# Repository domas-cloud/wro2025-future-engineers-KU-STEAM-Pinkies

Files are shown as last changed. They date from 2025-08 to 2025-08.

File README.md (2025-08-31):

# 🤖 WRO 2025 Future Engineers – KU STEAM Pinkies

   

Welcome to our official repository for **WRO 2025 Future Engineers Challenge**!  

We are **KU STEAM Pinkies**, a passionate team of young engineers building an **autonomous robot car** capable of navigating real-world tracks, avoiding obstacles, and detecting checkpoints.

---

## 👥 Team Introduction

**Team Members & Roles**
- **Marius** – Programmer & Mechanical Designer  
- **Domas** – Manager, Marketing & Testing  
- **Jonas** – Electronics Specialist & Designer  

**Our Goal:**  
To design and build a reliable autonomous robot that can perceive its environment, make decisions in real time, and drive smoothly and safely.

---

## 📚 Documentation

Our development process is fully documented:

- 🧠 [Brainstorming](docs/brainstorming.md)
- 📝 [Planning](docs/planning.md)
- ⚙️ [Hardware](docs/hardware.md)
- 🛠️ [Mechanical Design](docs/design.md)
- ⚡ [Power & Sense Management](docs/power_management.md)
- 💻 [Software / Code](docs/code.md)
- 🧪 [Testing](docs/testing.md)
- 📊 [Evaluation](docs/evaluation.md)
- ❗ [Encountered Problems and Solutions](docs/Encountered_Problems_and_Solutions.md)
 
---

## ⚙️ Hardware Overview

- **Arduino Mega 2560** – main controller (sensors + decision-making)  
- **Raspberry Pi Zero 2** – handles camera vision, communicates with Arduino via Serial  
- **Adafruit Motor Shield V2** – motor driver (DC + Servo)  
- **TOF sensors (VL53L1X)** – distance & obstacle detection (front + sides)  
- **TCS34725 Color Sensor** – detects orange/blue track lines for checkpoint counting  
- **Servo motor (SG90)** – precise steering  
- **DC motor + gear reduction + bearings** – smooth driving with torque optimization  
- **Li-ion batteries** – powering Arduino + motors  
- **Power bank** – powering Raspberry Pi for stable 5V  

---

## 💻 Software Overview

The software is based on a **three-layer architecture**:

1. **Obstacle Detection** (sensors)  
2. **Navigation** (error calculation + decision making)  
3. **Control** (PD steering + motor speed regulation)  

### 🔑 Step-by-Step Flow
1. **Sensor Reading** – TOF + color sensor data  
2. **Error Calculation** – compare measured distance vs desired trajectory  
3. **PD Control** – proportional + derivative parts for stable steering  
4. **Servo Steering** – adjusts angle based on PD output  
5. **Motor Update** – base speed / slow down / stop depending on obstacles  
6. **Obstacle Logic** – stop, bypass, or continue safely  

### 💬 Extra Features
- **Safety stop** if all sensors fail  
- **Servo angle limits** to avoid mechanical stress  
- **Base driving mode** if no obstacles detected  
- **Color sensor** counts **checkpoints** (orange & blue lines)  

---

## ▶️ How to Run the Code

### 1. Clone the Repository with Submodules
```bash
git clone --recurse-submodules https://github.com/domas-cloud/wro2025-future-engineers-KU-STEAM-Pinkies.git
cd wro2025-future-engineers-KU-STEAM-Pinkies
git submodule update --init --recursive
```

### 2. Open in PlatformIO
- Install [PlatformIO](https://platformio.org/) (VSCode extension or CLI).  
- Target board: **Arduino Mega 2560**.  

### 3. Build & Upload
```bash
pio run
pio run -t upload
```

### 4. Monitor Serial Output (optional)
```bash
pio device monitor
```

---

## 📚 Required Libraries

Make sure the following libraries are installed in PlatformIO or Arduino IDE:  

- `Adafruit Motor Shield V2 Library`  
- `Adafruit VL53L1X`  
- `Adafruit TCS34725`  
- `Wire` (I2C)  
- `Servo`  

---

## ⚠️ Limitations & Known Issues

### 1. Ultrasonic Sensors (Initial Tests)  
- In the early prototype, we used **HC-SR04 ultrasonic sensors**.  
- **Problems encountered:**  
  - Narrow field of view.  
  - Inaccurate measurements on uneven or angled surfaces.  
  - “Blind spots” in curves.  
- Because of these limitations, we switched to **VL53L1X TOF sensors**, which provide faster and more reliable distance readings.

### 2. TOF (VL53L1X) Sensors  
- Sometimes inaccurate on **very shiny** or **black matte** surfaces.  
- Multiple TOFs on the same I2C bus require **address reassignment** in software to avoid conflicts.  

### 3. TCS34725 Color Sensor  
- Strong ambient light can interfere with detection.  
- Close color shades (similar orange/blue tones) sometimes cause **false checkpoint counts**.  

### 4. PD Control (No Integral Part)  
- Without the integral (I) term, **steady-state error** may occur (e.g., robot stays closer to one wall).  
- In very sharp turns, PD sometimes results in **over-steering**.  

### 5. Mechanical Limitations  
- Single DC motor + gear system does not provide perfectly stable speed.  
- Bearings reduced friction, but on longer tracks, slight **speed fluctuations** remain.  

### 6. Raspberry Pi Zero 2  
- Too weak for **real-time image processing**.  
- Cannot run complex ML/AI models effectively.  

### 7. Power Supply Issues  
- When batteries are low, the **servo and DC motor** become unstable.  
- A **voltage monitoring system** would help stop the robot before malfunction.  

✅ Despite these limitations, the system is **robust enough for competition use**, and each issue points toward **clear upgrade paths** for future iterations.

---

## 🔮 Future Improvements

- Add an **integral part (I)** for full PID control  
- Implement **adaptive PID tuning** (self-adjusting Kp & Kd)  
- Improve obstacle avoidance with **dynamic path planning**  
- Use **machine learning** on Raspberry Pi to optimize driving  
- Add **IMU + encoders** for precise navigation  
- Implement **battery monitoring & current sensing** for reliability  

---

## ✅ Summary

Our robot behaves like a human driver:  
1. **Look** → read sensors (TOF + Color)  
2. **Decide** → calculate errors & detect obstacles  
3. **Act** → adjust steering + motor speed  

With PD control, the car drives smoothly, avoids obstacles, and counts checkpoints reliably.  

---

## 📜 License
This project is licensed under the **MIT License** – feel free to use, modify, and share with credit.

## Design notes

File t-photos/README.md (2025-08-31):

# KU Steam Pinkies Team

oficial

Here you can see the team members' arrangement:

- **Domas** – left  
- **Marius** – center  
- **Jonas** – right

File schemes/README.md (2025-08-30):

# 🔌 Electronics Diagrams

We designed and tested two wiring configurations for our robot: one with **5 ToF sensors only**, and one with **3 ToFs + IMU**. Both share the same **core PD control algorithm** – only the sensor inputs differ.

---

## 📐 Variant A – Without IMU (5× ToF)

**Description:**  
- **Arduino Mega 2560** is the main controller.  
- **5× VL53L1X ToF sensors** connected to the I²C bus (SDA/SCL).  
- Each ToF has an **XSHUT** line connected to a digital pin on Arduino to assign unique I²C addresses during initialization.  
- Optional **GPIO1/INT** lines can be connected for interrupts (not required).  
- **Motor/Servo module** controls the steering servo (PWM) and the DC drive motor (PWM).  

**Power:**  
- ToFs powered at 3.3 V, common GND with Arduino.  
- Servo + motor require stable 5–6 V supply (separate BEC recommended).  

📄 *See schematic:* [`Without IMU.pdf`](Without%20IMU.pdf)

---

## 📐 Variant B – With IMU (3× ToF + IMU)

**Description:**  
- **Arduino Mega 2560** is again the main controller.  
- **3× VL53L1X ToFs** on the same I²C bus.  
- **IMU sensor** (gyroscope + accelerometer) also connected to I²C, providing yaw/gyro data.  
- ToF **XSHUT** pins used for unique addressing as before.  
- **IMU INT** (interrupt) optionally connected to a digital input for faster reaction.  
- **Motor/Servo module** wiring unchanged (PWM).  

**Power:**  
- IMU powered at 3.3 V, ToFs also at 3.3 V.  
- Common GND required.  
- Servo/motor powered separately as in Variant A.  

📄 *See schematic:* [`with IMU.pdf`](with%20IMU.pdf)

---

## ⚖️ Comparison

| Feature | Without IMU (5 ToFs) | With IMU (3 ToFs + IMU) |
|---|---|---|
| Distance sensing | 5 directions (wider view)  | 3 directions + orientation |
| Orientation correction | From ToF geometry | From IMU (yaw/gyro) |
| I²C addressing | 5× ToF via **XSHUT** | 3× ToF via **XSHUT**, IMU fixed address |
| Wiring complexity | More ToFs, more lines | Fewer ToFs, extra IMU |
| Algorithm | **Same PD control** | **Same PD control** |

---

## 📝 Notes

- **Algorithm remains unchanged** in both cases (PD wall-following + motor control).  
- The only difference is the **sensor input**: either 5 ToFs, or 3 ToFs + IMU fusion.  
- Using IMU gave smoother turns and compensated for missing ToFs.  
- Proper power isolation (separate BEC for servo/motor, decoupling capacitors) is critical to avoid resets.  

---

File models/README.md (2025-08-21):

# Robot Structure

The robot consists of three engineering parts: **the movement system**, **the steering system**, and **the frame**.

---

## Movement System
The movement system is made of a gear mechanism that **increases torque** and **reduces speed**.  
This is necessary because the motor operates at a very high speed.  
All gear connections are lubricated with oil to reduce friction and wear, and **bearings are used to ensure smoother rotation and durability**.  
The movement system parts are **3D-printed**.

---

## Steering System
The steering system is based on a **gear and rack** principle.  
It is designed so that the rack moves only to the right or left, without shifting sideways.  
This prevents:
- stress on the servo mechanism,  
- gear teeth slipping,  
- inaccurate turns.  

The steering system parts are also **3D-printed**.

---

## Frame
The frame is made of **plywood** and is **laser-cut**.  
It consists of several levels with a compact removal system.  
This allows the robot to be disassembled more easily — for example, if the movement system breaks, several plates can be removed at once without dismantling the entire robot.  

The multi-level structure:
- makes the design clearer,  
- reduces the robot’s width and length,  
- provides a more organized and aesthetic appearance.

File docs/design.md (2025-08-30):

# 🛠️ Mechanical Design

## 🚗 Chassis Structure

The car chassis is designed to ensure:
- Stable driving on straight sections and in turns.  
- Sufficient space for electronics and wiring.  
- Optimal weight balance between the front and rear axles.  

The main construction is based on a **layered plywood (“stacking”) system** – this allows creating multiple levels for electronics while keeping the structure lightweight but strong.  

---

## 🔧 Component Layout

- **DC motor with gear reduction** mounted at the rear.  
  - 3D-printed gear reducers increase torque and reduce speed for more stable driving.  

- **Steering mechanism with servo** uses a **rack-and-pinion gear system** (3D-printed).  
  - The servo’s rotary motion is converted into linear rack motion.  
  - Ensures precise and durable steering compared to direct servo mounting.  

- **Arduino Mega** placed in the center of the chassis to minimize cable lengths.  

- **Batteries** located close to Arduino for compact wiring.  

---

## 📡 Sensor Placement Variants

### Variant A – Without IMU (5× ToF sensors)
- **Front ToF** – obstacle detection.  
- **Four side ToFs** (two on each side) – wall-following and angle measurement.  
- Purely geometric control from multiple distance points.  

### Variant B – With IMU (3× ToF + IMU)
- **Front ToF** – obstacle detection.  
- **Two side ToFs** (front + rear on one side) – Δx calculation for wall alignment.  
- **IMU** – provides yaw/orientation for turns, compensates for fewer ToFs.  
- Same **PD algorithm**, but input data comes from ToFs + IMU fusion.  

---

## 🛠️ Design Rationale

- The **plywood stacking system** provides flexibility – layers can be reconfigured quickly.  
- **3D-printed gear reducers** allow torque customization per track.  
- **Rack-and-pinion steering** ensures reliability and prevents servo overload.  
- **Lower center of gravity** improves stability in sharp turns.  
- **Modular layout** makes it easy to swap faulty sensors (as proven by IMU fallback integration).  

---

## 🔮 Future Development Opportunities

- Create a **protective 3D-printed body shell** to safeguard electronics.  
- Upgrade the **gear rack system** with metal parts for long-term durability.  
- Integrate a **suspension system** for tracks with uneven surfaces.  
- Add **mounting slots for spare sensors**, so replacement in emergencies is quicker.  

---

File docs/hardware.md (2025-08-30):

# ⚙️ Hardware Documentation

## 🧩 Used Components

- **Arduino Mega 2560**  
  Main control microcontroller responsible for reading all sensors and controlling the motors.  
  - Large memory and many I/O pins compared to Arduino Uno  
  - Handles sensor fusion, obstacle avoidance, and communicates with Raspberry Pi  

- **Raspberry Pi Zero 2**  
  - Processes camera data (line / object detection)  
  - Sends simplified results to Arduino over serial (115200 baud)  
  - Offloads heavy tasks (image recognition) from Arduino  

- **Adafruit Motor Shield V2**  
  - Motor driver shield, controls DC motor via I2C  
  - Provides PWM speed regulation, H-bridge for direction control  
  - Leaves most Arduino pins free  

- **TOF Sensors (VL53L1X)**  
  - Millimeter-accurate time-of-flight sensors  
  - **Front sensor** → obstacle detection  
  - **Side sensors** → track centering  
  - More precise and reliable than ultrasonic sensors  

- **IMU (gyro + accelerometer)**  
  - Added as fallback when two ToFs burned out  
  - Provides yaw/orientation feedback  
  - Used together with side ToFs for stable turns  

- **Color Sensor (TCS34725)**  
  - Reads RGB + clear light via I2C  
  - Used to **detect and count orange & blue lines** on the track  
  - Essential for lap counting and checkpoints  

- **Servo Motor (SG90)**  
  - Controls front steering mechanism  
  - PWM control from Arduino  
  - Software-limited range to prevent oversteering  

- **DC Motor**  
  - Drives the robot forward/backward  
  - Controlled through Motor Shield with PWM  
  - Gear reduction for torque & smoother motion  
  - Bearings used in drivetrain for efficiency  

- **Li-ion Batteries**  
  - Power Arduino, Motor Shield, motors, and sensors  
  - High energy density & rechargeability  

- **Power Bank**  
  - Dedicated 5V supply for Raspberry Pi  
  - Isolates Pi from motor power spikes  

---

## 🔀 Configurations

### Variant A – Without IMU (5× ToF)
- 5× VL53L1X on I²C bus (unique addresses via XSHUT).  
- Front ToF → obstacle detection.  
- Four side ToFs → distance and angle measurement.  
- Pure geometry-based alignment.  

### Variant B – With IMU (3× ToF + IMU)
- 3× VL53L1X on I²C bus.  
- IMU on same I²C bus for yaw/orientation.  
- Side ToFs still used for Δx calculation.  
- IMU yaw stabilizes turns, compensates for missing sensors.  
- Same PD algorithm, only input sources changed.  

---

## 🔌 Wiring Diagram (textual)

- **Arduino Mega ↔ Motor Shield V2**: I²C bus  
- **DC Motor** → Motor Shield **M1**  
- **Servo Motor** → Arduino **D9 (PWM)**  
- **TOF Sensors (VL53L1X)** → I²C (SDA, SCL), **XSHUT** pins to digital pins for addressing  
- **IMU** → I²C (SDA, SCL), optional INT pin to digital input  
- **Color Sensor (TCS34725)** → I²C (same bus)  
- **Li-ion Battery Pack** → Arduino Mega + Motor Shield  
- **Raspberry Pi Zero 2** ↔ Arduino Mega → Serial (TX/RX, 115200 baud)  
- **Raspberry Pi Camera** → Pi camera port  
- **Power Bank → Raspberry Pi** (stable 5V supply)  

---

## 🛠️ Component Selection Justification

- **Arduino Mega** → many peripherals at once, strong I/O support  
- **Raspberry Pi Zero 2** → dedicated vision processor, avoids overloading Arduino  
- **Motor Shield V2** → reliable I²C control, PWM, H-bridges included  
- **TOF sensors** → accurate, fast, unaffected by surface angles (better than ultrasonic)  
- **IMU** → essential fallback orientation, low-cost redundancy  
- **Servo motor** → accurate steering vs DC continuous motors  
- **DC motor w/ gear reduction** → torque + smooth control  
- **Li-ion + Power bank separation** → isolates Pi from noisy motor voltage  

---

## 📦 Hardware Expansion Possibilities

- Add **wheel encoders** → closed-loop speed & distance tracking  
- Add **current sensors** → detect stalls / overload  
- Add **battery monitoring** → prevent low-voltage damage  
- Upgrade to **Raspberry Pi 4** → enable advanced vision (object detection, SLAM)  
- Add **Wi-Fi / Bluetooth** → for remote debugging & telemetry  

---

## 📑 Schematics

- [Without IMU (5× ToF)](../schemes/Without%20IMU.pdf)  
- [With IMU (3× ToF + IMU)](../schemes/with%20IMU.pdf)

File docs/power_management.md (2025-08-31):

# Power & Sense Management

## Architecture

- **Drive:**  
  2S Li-ion pack (~7.4 V) → Adafruit Motor Shield V2 → DC motor.

- **Logic + vision:**  
  Power bank 5 V → Arduino Mega 2560 + Raspberry Pi Zero 2.

- **Steering servo:**  
  Powered from Arduino 5 V rail.  
  Control via PWM signal from Arduino Mega pin (D8).

- **Sensors:**  
  ToF VL53L1X (3–5 units) and IMU MPU-6050 connected via Arduino I²C.

---

## Power budget

| Subsystem | Voltage (V) | Nominal current (A) | Peak current (A) |
|---|---:|---:|---:|
| DC motor | 7.4–12 | 0.4–0.6 | **0.8** |
| Motor Shield V2 (limit) | — | — | **3.0** |
| Arduino Mega 2560 | 5 | 0.07 | 0.10 |
| Raspberry Pi Zero 2 | 5 | 0.35 | 0.8 |
| Steering servo (Arduino 5 V) | 5 | 0.20 | 1.0–1.5 |
| VL53L1X ToF (×3–5) | 5 | 0.06–0.10 | 0.12 |
| IMU MPU-6050 | 3.3–5 | 0.003–0.010 | 0.02 |

---

## Batteries and sources
- **2S Li-ion pack:** ~7.4 V, ≥1500 mAh.  
- **Power bank:** 5 V, must supply at least 2 A.  

---

## Calculations
- **Drive branch:** ~0.7–1.1 A average.  
- **2S 2000 mAh** → about 1.5–2 h runtime.  
- **5 V branch:** ~0.75–1.2 A (Arduino + RPi + servo + sensors).  
- Power bank must reliably provide ≥2 A.  

---

## Monitoring and testing
- **2S voltage:** measured via divider into Arduino ADC.  
- Tests: no-load → straight run → sharp turns → obstacle-stop → 5 min endurance.  

---

## Summary
- Two power sources: 2S Li-ion (drive) and Power bank 5 V (logic, servo, vision).  
- Motor max ~0.8 A (safely below 3 A Motor Shield limit).  
- Servo powered from Arduino 5 V and controlled directly from Arduino PWM pin.  
- Sensors: ToF and MPU-6050 connected via I²C.

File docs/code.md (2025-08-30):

# 💻 Software Idea and Implementation

## 🧠 Main Idea

The goal of our code is to ensure that the car drives stably, can detect obstacles, and adapts to the track shape.  
For this, we use a **three-layer architecture**:  
1. **Obstacle Detection**  
2. **Navigation**  
3. **Control**

---

## 🔑 Step-by-Step Code Flow

### 1. Sensor Reading
- The program first reads the **TOF sensors** (front + sides).  
- If one sensor returns an invalid value, the program assigns a maximum distance so that a faulty signal does not cause sudden braking.  
- The car always first “looks at the environment,” checks the front and side distances, and only then makes decisions.  

---

### 2. Error Calculation
- The measured data is compared to the desired distance from the wall or the center of the track.  
- The difference (**error**) shows how much the car has deviated.  
- If the car is too close to the wall → error positive.  
- If too far → error negative.  
- This error becomes the main indicator used to adjust the steering.  

---

### 3. PD Control Algorithm
- The control signal consists of:  
  - **Proportional part (P)** → how much the car has deviated.  
  - **Derivative part (D)** → how quickly that deviation is changing.  
- The car not only sees *how much* it deviates, but also *how fast* it happens.  
- This prevents oscillation from side to side.

---

### 4. Steering Servo Control
- The PD output is converted into a **steering angle**.  
- Large error → strong steering correction.  
- Small error → slight correction.  
- Steering values are limited in software so the servo does not exceed its physical range.  

---

### 5. Motor Update
- The **DC motor** is controlled through the Adafruit Motor Shield.  
- If sensors show a clear path → base speed is maintained.  
- If an obstacle is detected → the motor slows down or stops.  
- At each cycle, the robot decides whether to **keep driving**, **slow down**, or **stop**.  

---

### 6. Obstacle Detection Logic
- If the **front TOF sensor** shows a distance smaller than safe, the robot stops.  
- If the obstacle is only on one side, the car adjusts steering to go around it.  
- If all sensors fail → the robot stops in **safety mode**.  

---
# 📏 How Distance to the Wall (d₁) is Calculated

The value **d₁** represents the **true perpendicular distance** from the robot’s side to the wall.  
It is calculated using **two TOF sensors** (front and rear) mounted on the same side of the robot.

---
## 🔹 Geometric Calculation of d₁

To obtain the true perpendicular distance to the wall, the robot uses two TOF sensors (front and rear).  
The diagram below shows how x₁ and x₂ are projected to calculate d₁:



Here:
- x₁ = front TOF measurement  
- x₂ = rear TOF measurement  
- L = distance between sensors  
- d₁ = perpendicular distance to the wall  
- d₂ = desired setpoint distance  

The angle φ is used to project the sensor readings, so the real distance is:  

d₁ ≈ ((x₁ + x₂) / 2) * cos(φ)   

---
## 🔹 Step 1 – Sensor Readings
- **x₁** = front TOF measurement (mm)  
- **x₂** = rear TOF measurement (mm)  
- **L** = longitudinal distance between the two sensors (mm)

---

## 🔹 Step 2 – Angle to the Wall
The tilt angle θ of the robot relative to the wall is computed as:

θ = arctan((x₂ - x₁) / L)

- If **x₁ < x₂** → the robot’s nose points **towards** the wall  
- If **x₁ > x₂** → the robot’s nose points **away** from the wall  

---

## 🔹 Step 3 – Perpendicular Distance
Since the sensors measure along their own axis (not perpendicular to the wall),  
the perpendicular distance is calculated as:

d₁ ≈ ((x₁ + x₂) / 2) * cos(θ)

---

## 🔹 Step 4 – Distance Error
The error used by the PD/PID controller is:

Δd = d₁ - d₂

Where **d₂** is the desired (setpoint) distance from the wall.

### Sensor Reading  
- In the fallback configuration, it also reads the IMU yaw.  

---

### Error Calculation  
- With IMU: yaw error is added to side distance error to stabilize turns.  

---

### PD Control Algorithm  
- With IMU: yaw correction is combined with side distance correction.  

---

# 🧭 Sensor Fusion (ToF + IMU Fallback)  

When only 3 ToFs are available:  
- Two side ToFs are used for distance alignment.  
- IMU provides yaw for orientation stability.  

This ensures stable turning even with fewer distance sensors.  
The PD control loop remains the same, only the sensor inputs are different.  

---

### 📚 Required Libraries  
- Adafruit Sensor (for IMU)  

# Obstacle Avoidance Algorithm

## 1. Object Detection with Camera
The robot uses a camera to detect colored objects.  
First, the system isolates the object of interest from the camera feed using a predefined color filter.  
The detected object represents a potential obstacle.

## 2. Distance Calculation
Once the object is detected, the system calculates its distance from the robot or from a reference wall.  
The distance is estimated based on the camera’s field of view, the object’s size in the image, and the robot’s current position.

## 3. Object Position Estimation
Using the processed camera data, the robot determines the object’s coordinates relative to its own position (x, y).  
This allows the robot to understand the exact location of the obstacle within its coordinate system.

## 4. Side Determination (Left/Right)
The system evaluates whether the detected object is located on the left or right side of the robot’s field of view.  
- If the object is on the left → the obstacle is considered left-side.  
- If the object is on the right → the obstacle is considered right-side.  

This decision defines the avoidance direction.

## 5. PD Control for Path Adjustment
Based on the obstacle position, the robot generates a corrected trajectory line that must be followed.  
A PD controller is then used to smoothly adjust the robot’s movement, ensuring it bypasses the obstacle while maintaining stable navigation.

---

### Summary
- **Camera** detects the colored obstacle.  
- **Distance & position** are calculated relative to the robot.  
- **Left/Right** determination defines avoidance direction.  
- **PID controller** follows an adjusted line to safely avoid the obstacle.

## 💬 Additional Logic
- **Safety stop** if all sensors give invalid values.  
- **Servo angle limits** to avoid gear skipping.  
- **Base driving mode** if no obstacles are detected.  
- **TCS34725 Color Sensor** is used to **detect and count orange and blue lines**, serving as checkpoints for lap counting.  

---

# ▶️ How to Run the Code

### 1. Clone the Repository with Submodules
```bash
git clone --recurse-submodules https://github.com/domas-cloud/wro2025-future-engineers-KU-STEAM-Pinkies.git
cd wro2025-future-engineers-KU-STEAM-Pinkies
git submodule update --init --recursive
```

---

### 2. Open the `src/` Folder in PlatformIO
- Install [PlatformIO](https://platformio.org/) (VSCode extension or CLI).  
- Target board: **Arduino Mega 2560**.  

---

### 3. Build & Upload
```bash
pio run
pio run -t upload
```

---

### 4. Monitor Serial Output (optional)
```bash
pio device monitor
```

---

# ⚙️ Hardware Setup

- **Arduino Mega** connected to **Adafruit Motor Shield V2** (I2C)  
- **DC motor** → Motor Shield M1  
- **Servo motor** → PWM pin (D9)  
- **TOF sensors (VL53L1X)** → I2C bus (SDA, SCL)  
- **Color sensor (TCS34725)** → same I2C bus  
- **Raspberry Pi Zero 2 ↔ Arduino Mega** via Serial (115200 baud)  
- **Power**: Li-ion batteries (Arduino + Motor Shield) + Power bank (Raspberry Pi)  

---

## 📚 Required Libraries
Make sure the following libraries are installed in PlatformIO or Arduino IDE:  
- `Adafruit Motor Shield V2 Library`  
- `Adafruit VL53L1X`  
- `Adafruit TCS34725`  
- `Wire` (I2C)  
- `Servo`  

---

## 🔮 Future Improvements
- Add an **integral part (I)** for full PID control to reduce long-term errors  
- Implement **adaptive PID tuning** so the robot can adjust Kp and Kd automatically  
- Improve obstacle avoidance to include **dynamic path planning**  
- Add **machine learning** (on Raspberry Pi) to optimize driving behavior  

---

## ✅ Summary
Our program works as follows:  

1. The robot **observes the environment** (sensors)  
2. It **calculates deviation** (error)  
3. It **adjusts steering and speed** (servo + DC motor)  

This process mimics human driving: **look → decide → act**.  
With PD control, the car drives smoothly, avoids obstacles, and counts checkpoints using color detection.

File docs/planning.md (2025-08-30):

# 🗓️ Planning

## 📅 Project Timeline

| Phase | Description | Responsible |
|---|---|---|
| 1. Problem definition | Define project goals and success criteria | Domas |
| 2. Idea generation | Create and compare multiple ideas | Whole team |
| 3. Design and CAD models | Draw sketches, 3D models, wiring diagrams | Marius, Jonas |
| 4. Hardware assembly | Assemble motors, sensors, and electronics | Jonas |
| 5. Programming | Develop control architecture, implement PD control | Marius |
| 6. Testing and iterations | Perform tests, collect data, improve system | Domas |
| 7. Final evaluation | Verify against goals and WRO rules | Whole team |
| 8. Documentation | Complete engineering journal, GitHub documentation | Domas |
| 9. Emergency adaptations | React to unexpected hardware failures (e.g. fallback to IMU) | Whole team |

---

## 📦 Resource Planning

### Hardware
- Arduino Mega 2560  
- Adafruit Motor Shield V2  
- TOF (VL53L1X) sensors (originally 5 planned, fallback with 3)  
- IMU (gyro + accelerometer) – integrated after ToF failures  
- Servo motor for steering  
- DC motor  
- Li-ion battery pack  

### Software & Tools
- Arduino IDE / PlatformIO  
- GitHub for version control and documentation  
- CAD software for mechanical and wiring diagrams  
- Logging/plotting tools for test data analysis  

---

## 👥 Team Task Distribution

- **Marius – Programmer and Mechanical Designer**  
  Coding, PD control implementation, CAD design, IMU integration.  

- **Domas – Manager, Marketing and Testing**  
  Project coordination, testing (including emergency fallback testing), documentation, communication.  

- **Jonas – Electronics Specialist and Designer**  
  Electronics assembly, ToF wiring, IMU addition, sensor calibration, power management solutions.  

---

## 🎯 Milestones

- **M1** – Problem clearly defined and documented  
- **M2** – First prototypes tested (5× ToF configuration)  
- **M3** – Stable driving system with obstacle detection  
- **M4** – *Emergency adaptation:* 3× ToF + IMU configuration validated before competition  
- **M5** – Final tests completed  
- **M6** – Full documentation submitted  

---

## ⚠️ Risk Management 

- Always prepare **spare sensors/components**.  
- Define a **fallback plan** (e.g. replace missing ToFs with IMU input).  
- Allocate time for **unexpected hardware failures** close to competition.

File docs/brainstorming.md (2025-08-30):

# 🧠 Brainstorming & Idea Generation

## Core Principles
- Reliability over speed – better to be a bit slower, but always working.  
- Simplicity is key – avoid overly complex solutions.  
- Iterative improvement – enhance step by step.  
- Testing over theory – everything is tested in practice.  
- Mistakes = data – failure means learning something new.  

---

## 💡 Initial Ideas

1. **Multi-layer control architecture (SCA model)**  
   - Obstacle layer – obstacle detection.  
   - Navigation layer – trajectory planning.  
   - Control layer – motor and steering control.  

2. **TOF (VL53L1X) sensors**  
   - Multiple accurate Time-of-Flight sensors for obstacle detection and distance measurement.  

3. **Motor Shield + DC motors**  
   - Adafruit Motor Shield V2 for motor control.  
   - Ensure sufficient torque and speed.  

4. **Servo mechanism**  
   - Servo for steering (front axle).  
   - Possibility to move an additional sensor if needed.  

5. **PD control**  
   - Proportional-Derivative control for stable steering.  
   - Smooth driving without sudden deviations.  

6. **AceSorting algorithms**  
   - Library-based data logic for decision-making.  

---

## ⚖️ Comparison of Alternatives

| Idea | Advantages | Disadvantages |
|---|---|---|
| Camera only (computer vision)| Can recognize signs, advanced analysis | Strongly depends on lighting, requires heavy computing |
| Ultrasonic sensors only | Simple and cheap | Low accuracy, sensitive to reflections |
| IMU only | Provides yaw and orientation | Drift over long distances, needs correction |
| Hybrid solution (TOF + PD) | Reliable, fault tolerant | Higher complexity, more testing required |

---

## ✅ Chosen Solution

We chose a **hybrid solution with multi-layer architecture**, including:  
- TOF sensors for obstacle detection.  
- PD control for trajectory and speed.  
- Servo mechanism for steering.  
- Motor Shield + DC motors.  
- AceSorting algorithms for data processing.  

This covers the weaknesses of single-technology approaches and ensures reliable performance on the WRO track.  

---

## 🔄 Rejected Ideas Justification

- **Camera** – rejected due to lighting dependence.  
- **Ultrasonic sensors** – rejected due to accuracy issues.  
- **IMU** – initially rejected due to drift errors.  

---

## 🔁 Decision Update (Competition Reality)

Three days before the competition, **two ToF sensors burned out**.  
- Original design: 5× ToFs.  
- Emergency fallback: **3× ToFs + IMU**.  

**Key points:**  
- The **core PD algorithm did not change** – only sensor inputs were updated.  
- Side wall-following still uses two ToFs.  
- IMU yaw compensates for reduced ToF coverage and stabilizes turns.  
- Robot remained functional and competition-ready.  

👉 Lesson learned: sometimes a **previously rejected idea (IMU)** becomes critical when hardware fails. Flexibility is as important as the initial design.

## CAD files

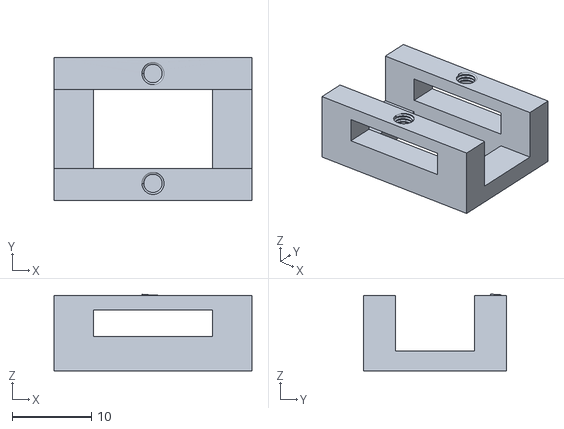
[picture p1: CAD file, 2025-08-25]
models/floors/cam holder.STL
25.0 x 18.0 x 9.70

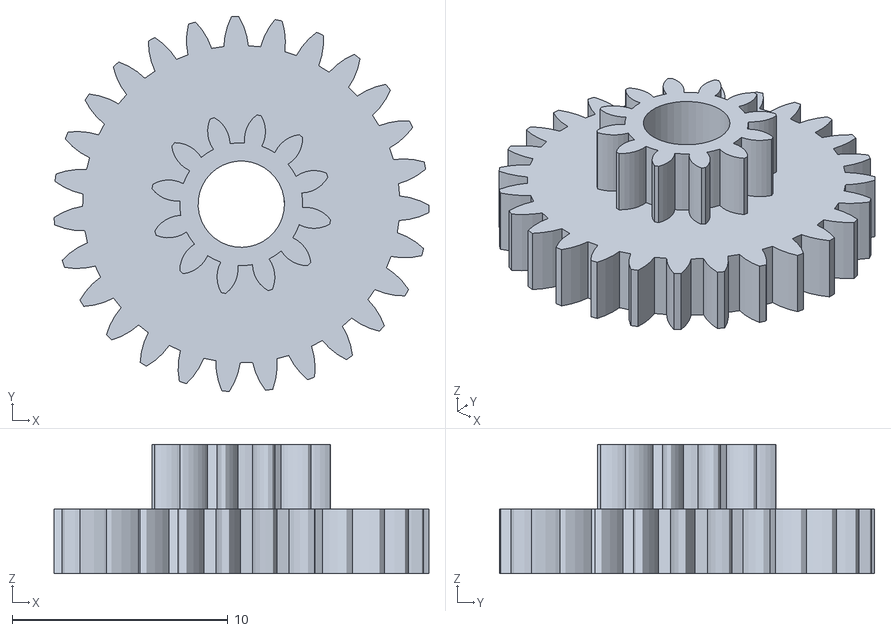
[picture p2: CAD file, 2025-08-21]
models/movement/Assem1-Part5Assem1-1 (6).stl
17.4 x 17.4 x 6.00

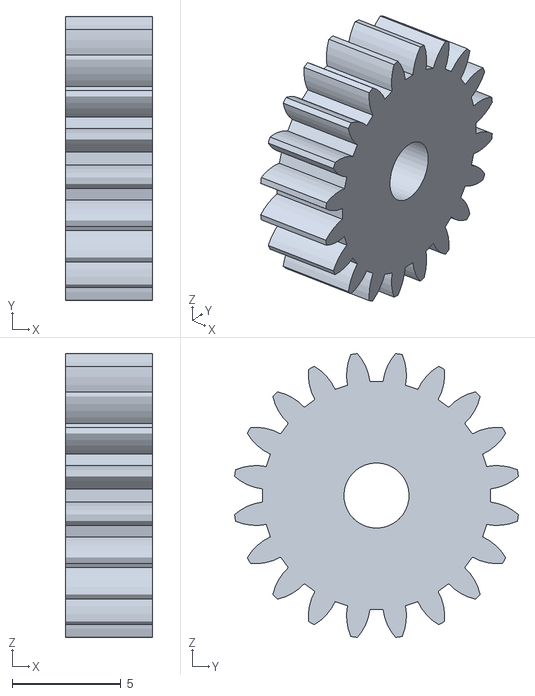
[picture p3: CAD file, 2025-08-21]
models/steering/servo-geart.stl
4.00 x 13.1 x 13.1

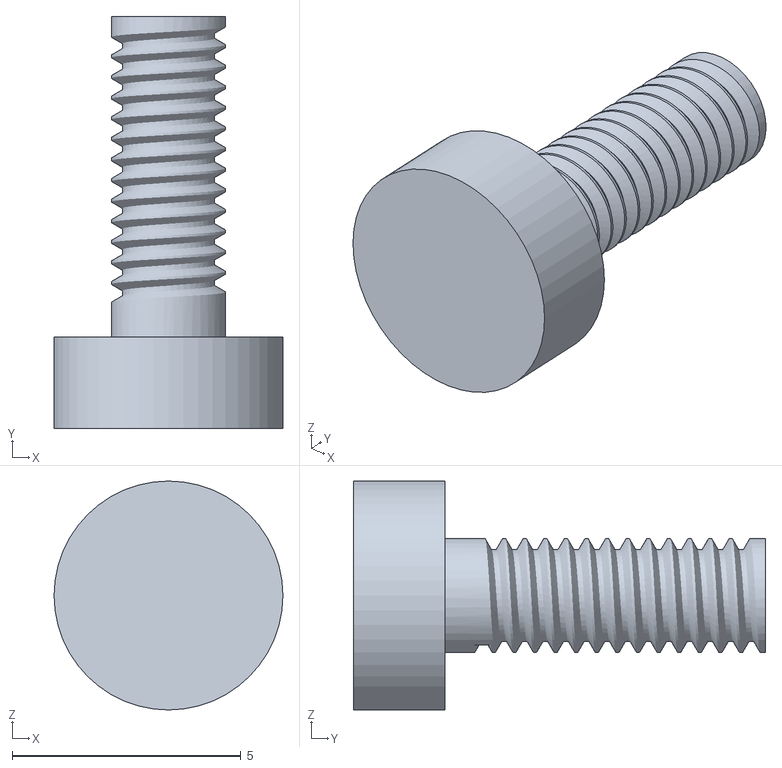
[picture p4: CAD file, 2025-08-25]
models/floors/varztas (1).STL
5.00 x 9.00 x 5.00

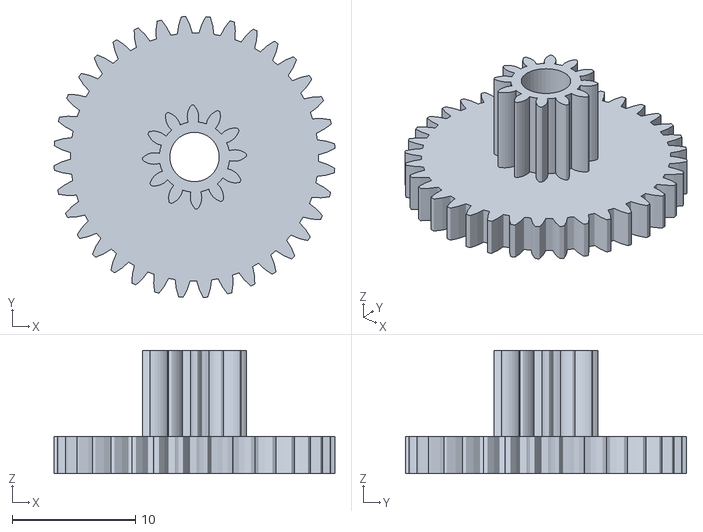
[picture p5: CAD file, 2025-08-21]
models/movement/Assem1-Part4Assem1-1 (4).stl
22.8 x 22.8 x 10.00

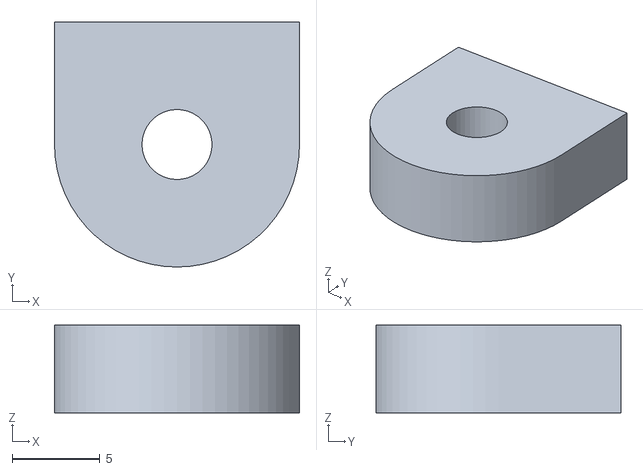
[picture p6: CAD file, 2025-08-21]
models/steering/paaukstintas.stl
14.0 x 14.0 x 5.00

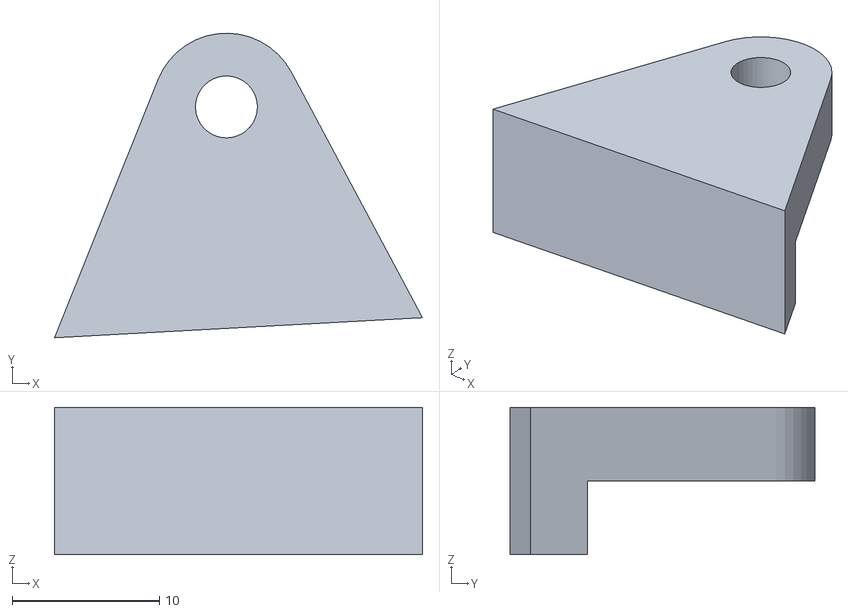
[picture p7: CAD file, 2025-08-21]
models/movement/Assem1-Part2Assem1-1 (2).stl
25.0 x 20.7 x 10.00

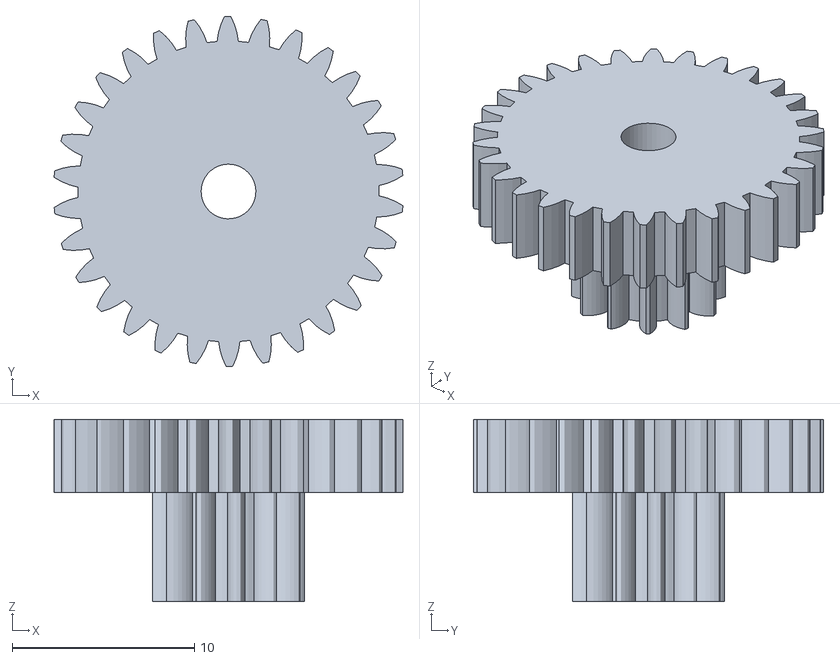
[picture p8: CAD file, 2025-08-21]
models/steering/rack-gear-v2 (2).stl
19.1 x 19.2 x 10.00

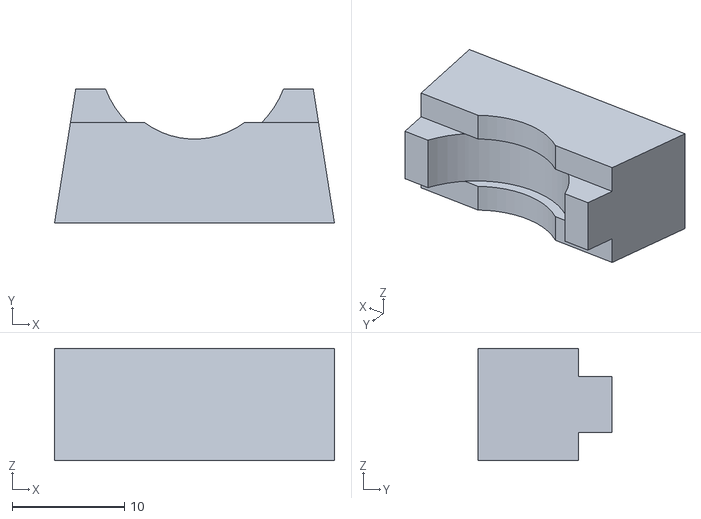
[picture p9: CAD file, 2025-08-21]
models/movement/bottom-holder (4).stl
25.0 x 12.0 x 10.0

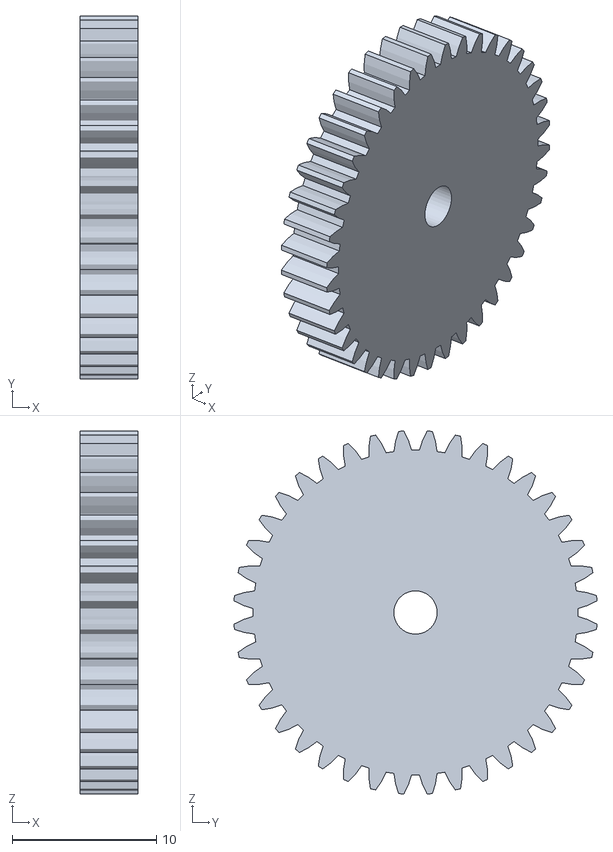
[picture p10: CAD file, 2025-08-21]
models/steering/servo-gear-v2 (1).stl
4.00 x 25.1 x 25.1

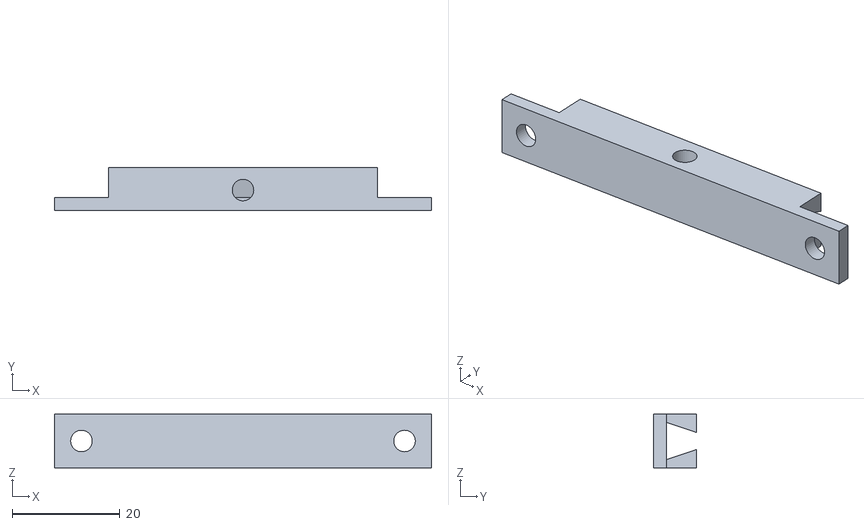
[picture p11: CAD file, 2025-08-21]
models/steering/SLIDDER-NAUJAS.stl
70.0 x 8.00 x 10.0

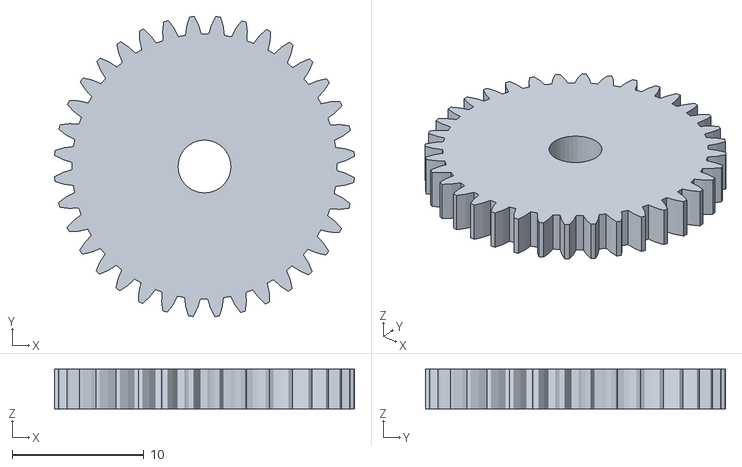
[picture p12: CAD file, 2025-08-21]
models/movement/Assem1-spur-gear_iso-8 (4).stl
22.7 x 22.7 x 3.00

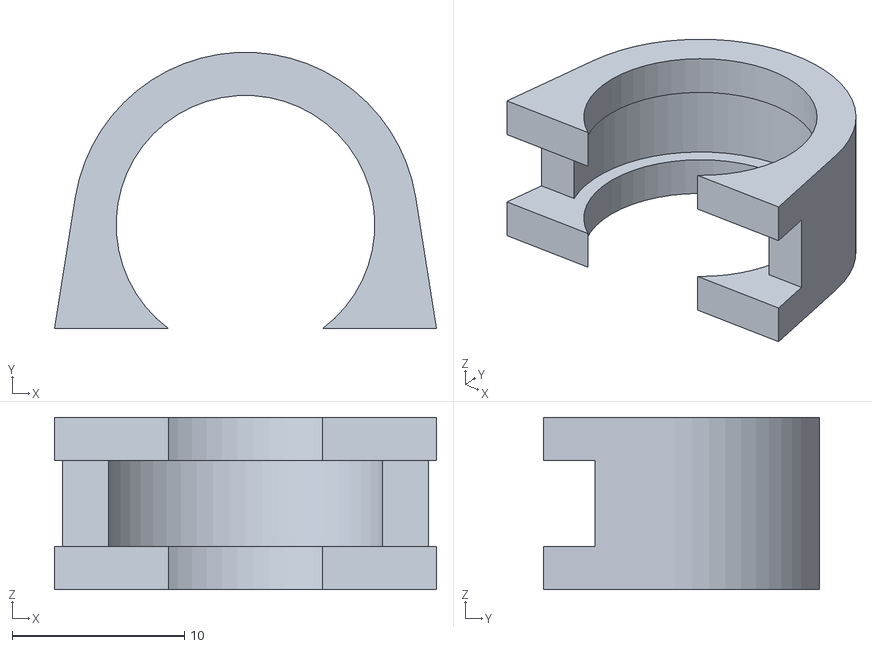
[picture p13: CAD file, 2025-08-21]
models/movement/top-holder (2).stl
22.2 x 16.0 x 10.0

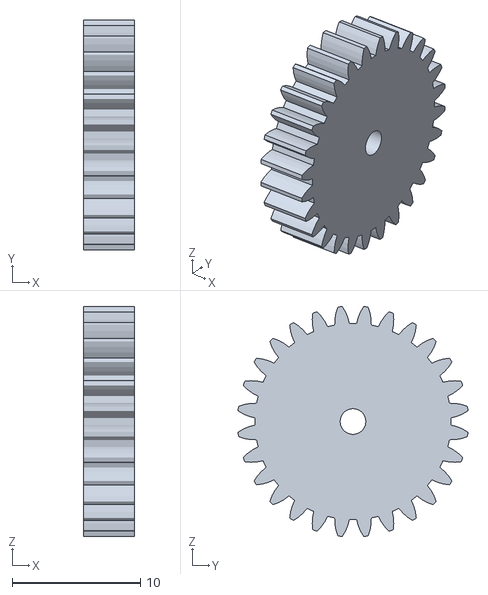
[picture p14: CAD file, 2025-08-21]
models/steering/spur-gear_iso.stl
4.00 x 17.9 x 17.9

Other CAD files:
models/steering/slider-pakeistaas.stl
models/steering/slider-latest.stl
models/steering/PAKEISTI-1.stl
models/steering/Part6vaziuokle (1).stl
models/steering/guolis1 (1).stl
models/steering/guolis2 (2).stl
models/steering/pakeisti-2.stl
models/steering/slider-gear (1).stl
models/steering/support (2).stl
models/steering/vazuokle-final-Part3vaziuokle-1 (2).stl
models/steering/vazuokle-final-rack-spur-rectangular_iso-4 (1).stl

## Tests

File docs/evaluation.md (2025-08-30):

# 📊 Evaluation

## ✅ Achievements
- Successfully integrated **Arduino Mega** with **Raspberry Pi Zero 2**, enabling real-time communication between camera processing and low-level control.  
- Implemented **TOF VL53L1X sensors** for accurate obstacle detection and trajectory maintenance.  
- Added a **Color Sensor (TCS34725)** that reliably detects and counts **orange and blue lines** for lap/checkpoint counting.  
- Developed a **rack-and-pinion steering system** driven by a servo, designed to avoid skew and prevent gear tooth skipping.  
- Implemented a **gear reduction drivetrain with bearings**, reducing friction while increasing torque for stable movement.  
- Created a **multi-level frame** that allows easy maintenance and compact assembly.  
- Designed and documented a complete hardware & software workflow, with clear repository structure and build instructions.  
- Successfully adapted the robot to a **fallback configuration (3 ToFs + IMU)** when two sensors failed just before competition, without changing the core PD algorithm.  

---

## ⚠️ Challenges & Limitations
- **Servo torque limitation**: the SG90 servo sometimes struggles under load, reducing steering precision at higher speeds.  
- **Camera processing**: the Raspberry Pi Zero 2 has limited performance, making advanced image recognition difficult in real time.  
- **Lighting conditions**: the color sensor is sensitive to changes in ambient light, which may affect orange/blue line detection.  
- **Battery management**: currently no automatic voltage monitoring – sudden drops can cause resets or unstable performance.  
- **PID/PD tuning**: requires manual calibration per environment; not yet fully adaptive.  
- **Sensor failures**: losing two ToFs forced an emergency adaptation; although IMU compensated well, reliability decreased compared to the original 5-sensor setup.  

---

## 💡 Lessons Learned
- Precise **mechanical design** (using bearings and correct gear ratios) significantly improves drivetrain reliability.  
- **Sensor fusion** is critical: combining TOF sensors with color detection provides much more robust navigation than using a single sensor type.  
- Splitting computation between **Arduino (real-time tasks)** and **Raspberry Pi (vision tasks)** is effective, but requires careful communication handling.  
- Documentation and version control (with submodules) save time and make the project easier to share with the team.  
- Having a **fallback plan** (IMU integration) can save the project when unexpected hardware failures occur.  

---

## 🚀 Future Improvements
- Upgrade the steering servo to a **higher-torque model** for more reliable control.  
- Replace the Raspberry Pi Zero 2 with a **Raspberry Pi 4** (or similar) for faster image processing and potential AI vision features.  
- Implement **adaptive PID control**, allowing the robot to auto-tune its parameters in different track conditions.  
- Improve **IMU integration** with advanced filtering (complementary/Kalman) to reduce drift.  
- Introduce **battery voltage monitoring** with automatic safe shutdown.  
- Optimize **color sensor calibration** by adding dynamic lighting compensation.  
- Improve modularity of the codebase for easier debugging and testing.  

---

## 🎯 Conclusion
Overall, our project demonstrates a **well-balanced integration of mechanical, electronic, and software systems**.  
Despite hardware and computational limitations, the robot is capable of autonomous navigation, obstacle avoidance, and line counting.  
The emergency switch to a **3 ToF + IMU hybrid configuration** proved that our system is flexible and resilient.  
We identified clear improvement areas and defined concrete next steps, which will guide the team toward building a more **robust, reliable, and competition-ready robot** for WRO 2025 Future Engineers.

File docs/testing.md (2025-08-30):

# 🧪 Testing

## 🎯 Testing Goals
- Evaluate the car's stability when driving on straight sections and in turns.  
- Verify the obstacle detection system and reaction time.  
- Tune the PD control parameters (Kp, Kd).  
- Ensure that the car complies with WRO rules.  

---

## 🧪 Test Scenarios

1. **Straight Line Test**  
   - Goal: evaluate if the car drives stably without oscillation.  
   - Expected result: deviation ≤ 5 cm from the track center.  

2. **90° Turn Test**  
   - Goal: check steering servo response and PD control in corners.  
   - Expected result: smooth turn without stopping.  

3. **Front Obstacle Detection Test**  
   - Goal: ensure the car stops in front of an obstacle.  
   - Expected result: stop ≤ 10 cm from the obstacle.  

4. **Side Obstacle Detection Test**  
   - Goal: verify that the car can avoid an obstacle.  
   - Expected result: turn to the opposite side while keeping trajectory.  

5. **Long-Term Driving Test**  
   - Goal: observe battery performance, sensor stability, and PD error accumulation.  
   - Expected result: the car maintains stable driving for at least 5 minutes.  

---

## 📊 Collected Data

- Sensor reading accuracy (mm).  
- Reaction time to obstacles (ms).  
- Maximum and average trajectory deviation (mm).  
- Energy consumption (battery runtime).  

---

## 🔄 Iterations

- Kp value decreased to reduce oscillation.  
- Kd value increased to improve cornering stability.  
- Safety limits added to restrict servo turning angle.  
- Implemented filtering of faulty sensor readings.  

---

## ✅ Results

- The car drives stably on straight sections.  
- Additional PD tuning required in corners.  
- Front obstacles detected reliably, stopping distance ~8 cm.  
- Obstacle avoidance logic still under testing.  

---

## 🧭 IMU + ToF Fallback Testing

When two ToF sensors failed shortly before the competition, the system was adapted to use **3 ToFs + IMU**.  
Additional tests were carried out to ensure stability:  

- **Sharp Turn Test with IMU**  
  - Goal: verify if IMU yaw helps smoother turning.  
  - Result: robot showed reduced oscillation compared to ToF-only setup.  

- **Stability Under Reduced Sensors**  
  - Goal: confirm that the PD algorithm still works with fewer distance sensors.  
  - Result: stable driving achieved, algorithm unchanged, only inputs adapted.  

- **Competition Simulation Run**  
  - Goal: full track drive with fallback configuration.  
  - Result: reliable driving, checkpoints detected, obstacle stop worked as expected.  

**Lesson learned:** IMU significantly improves stability when ToF coverage is reduced, and having a fallback plan was crucial for competition readiness.  

---

## 🔮 Next Steps

- More precise PD tuning in different track conditions.  
- Improvement of obstacle avoidance algorithms.  
- Automatic adaptation of Kp and Kd values based on speed.

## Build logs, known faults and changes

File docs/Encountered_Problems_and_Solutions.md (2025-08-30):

# Encountered Problems and Solutions

## Burned ToF Sensors Before Competition
**Problem:**  
Three days before the competition, two of our VL53L1X ToF sensors burned out due to wiring or power instability. Our original design used 5 ToFs for precise wall-following and obstacle detection.

**Solution:**  
- Reconfigured the system to work with **3 ToFs** only (two on the side, one in the front).  
- Integrated **IMU data (gyroscope + accelerometer)** to support orientation and turning.  
- **The core control algorithm (wall-following with PD correction) remained the same** – we only changed how sensor data is fed into it.  
  - Side alignment (Δx) still calculated from the two side ToFs.  
  - Yaw stability and smoother turning compensated with IMU feedback.  

**Result:**  
Robot remained functional and competition-ready. Even though distance precision decreased slightly, IMU fusion gave us reliable performance and smoother turns.

---

## Sensor Addressing Conflicts
**Problem:**  
When using multiple VL53L1X sensors on the same I²C bus, we encountered address conflicts. Sometimes sensors would not respond correctly or gave inconsistent readings.

**Solution:**  
- Implemented a sensor initialization sequence to assign unique I²C addresses for each ToF.  
- Added error-handling logic to re-initialize sensors if no data was received.  

**Result:**  
Stable multi-ToF operation without random dropouts.

---

## Power Spikes on Servos
**Problem:**  
During sharp turns, the steering servo caused voltage dips that interfered with sensors and occasionally reset the controller.  

**Solution:**  
- Added a separate BEC regulator for the servo.  
- Introduced capacitors for smoothing voltage spikes.  

**Result:**  
No more brownouts; reliable operation under full load.

---

## Limited Testing Time
**Problem:**  
Due to hardware failures and late fixes, we had limited time to test the robot on a real track.  

**Solution:**  
- Focused on the most critical test cases: sharp turns, obstacle avoidance, and recovery.  
- Logged data from each run and adjusted PD parameters iteratively.  
- Ensured that even with limited tests, the robot could handle all essential competition scenarios.  

**Result:**  
Despite reduced testing time, the robot performed consistently within competition rules.

---

# Lessons Learned
- Always prepare spare critical sensors and components.  
- IMU can successfully compensate for missing distance sensors without changing the core algorithm.  
- Power management is crucial for reliable operation.  
- Systematic logging and quick iteration allow recovery even under time pressure.  
- Flexibility and adaptability are as important as initial design.

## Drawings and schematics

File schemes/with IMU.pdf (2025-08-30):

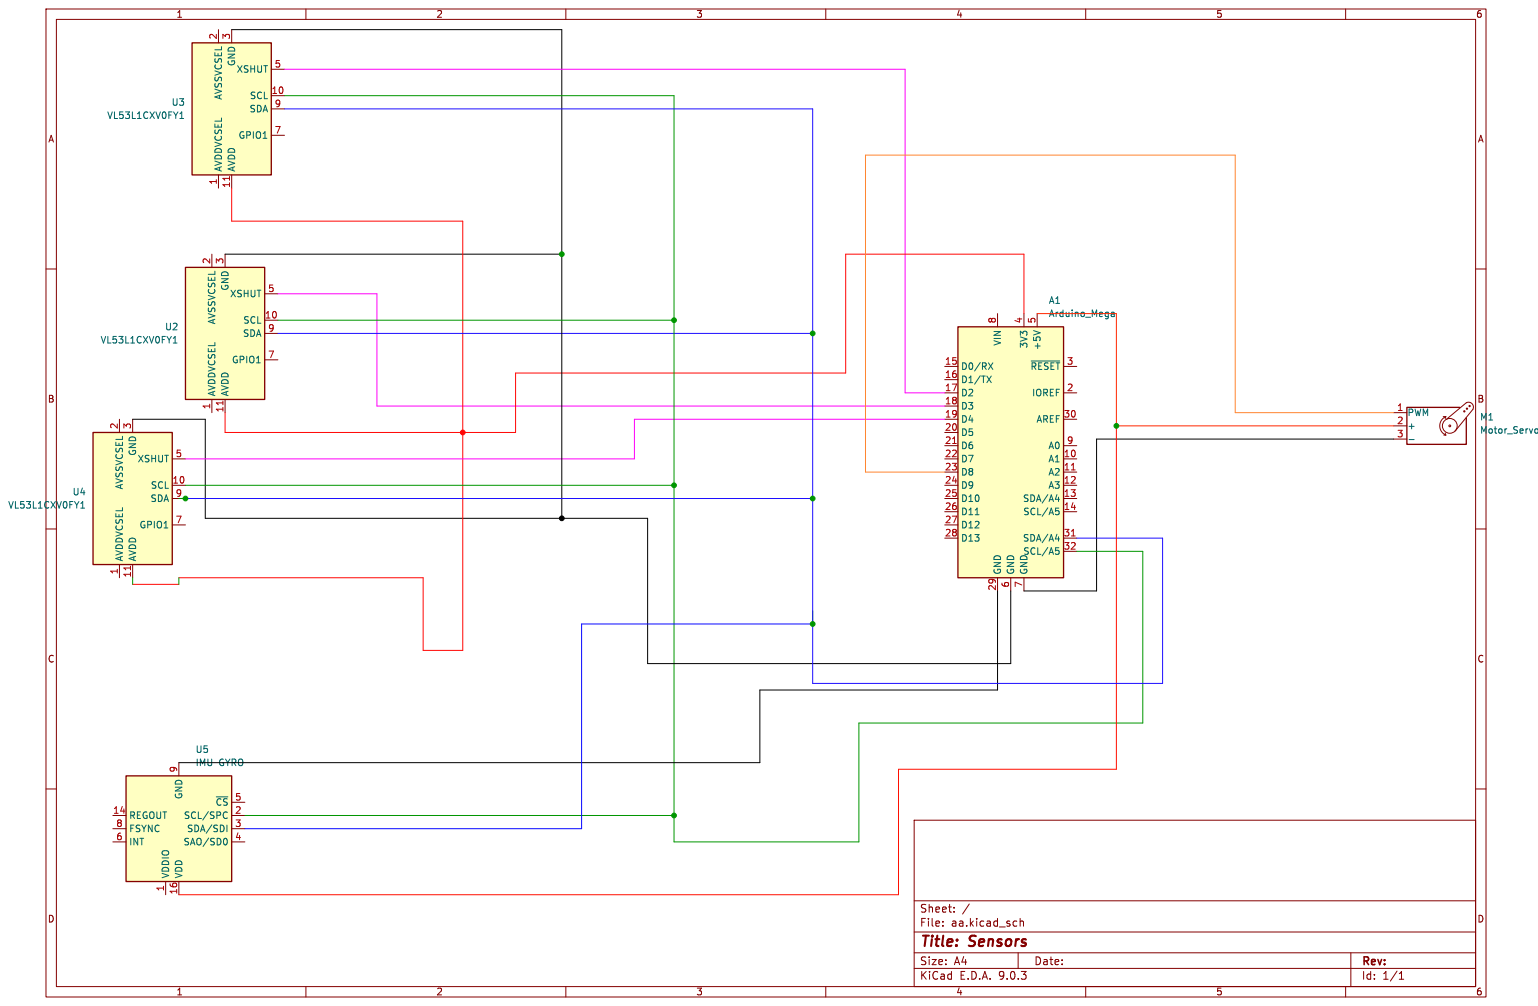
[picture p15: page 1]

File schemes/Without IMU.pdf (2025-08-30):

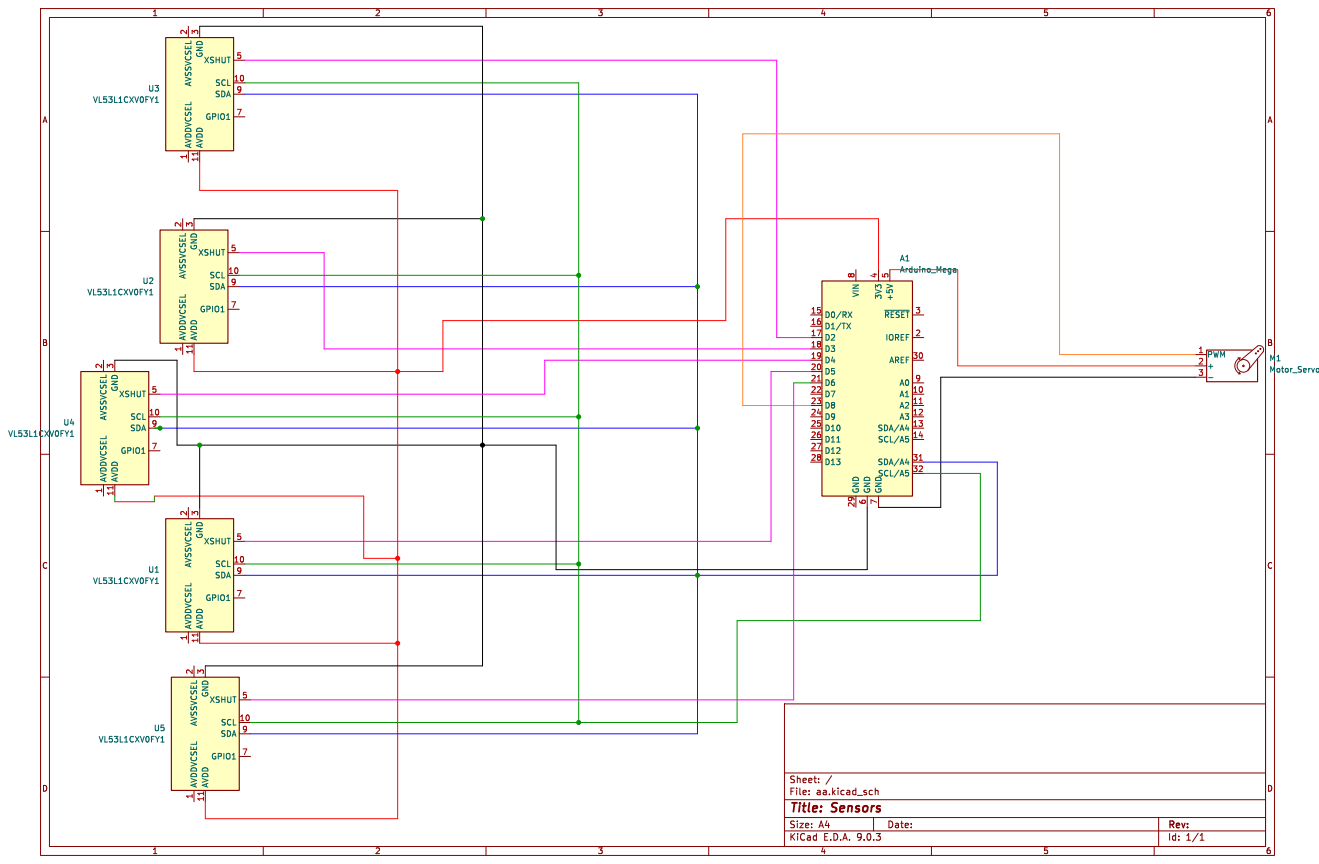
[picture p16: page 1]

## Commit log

2025-06-12 Rename support (1).stl to support.stl
    [support.stl]
2025-06-12 Rename guolis1 (2).stl to guolis1.stl
    [guolis1.stl]
2025-06-12 Rename guolis2 (1).stl to guolis2.stl
    [guolis2.stl]
2025-06-12 Rename vazuokle-final-slider-1 (1).stl to vazuokle-slider.stl
    [vazuokle-slider.stl]
2025-06-12 Rename vazuokle-final-Part3vaziuokle-1 (1).stl to vazuokle-final-vaziuokle-1.stl
    [vazuokle-final-vaziuokle-1.stl]

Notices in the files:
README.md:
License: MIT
